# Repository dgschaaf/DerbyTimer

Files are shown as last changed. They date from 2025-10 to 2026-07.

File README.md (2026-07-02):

# DerbyTimer

Pinewood derby timing and race track control system.

**Author:** Darren Schaaf  
**Documentation guide:** [docs/README.md](docs/README.md)

---

## System Overview

DerbyTimer is a two-controller embedded system that manages the complete lifecycle of a pinewood derby race -- from staging and countdown through finish line detection and result display.

```
[Start Controller]  ──── UART 115,200 baud ────  [Finish Controller]
 Arduino Nano (ATmega328P)                         Arduino Nano 33 BLE (nRF52840)
 Custom PCB shield                                 Custom PCB shield
```

The **Start Controller** manages gates, lights, buttons, and race sequencing. The **Finish Controller** measures finish times, drives result displays, and determines the winner. Both run independent state machines that stay synchronized over a serial protocol.

---

## Race Modes

| Mode | Behavior |
|---|---|
| Gate Drop | Both gates release simultaneously; no reaction time |
| Reaction Time | Cars held at gate; release time measured per lane |
| Pro Tree | Accelerated countdown sequence (400 ms steps) |
| Dial-In | BLE-activated only (Race Manager required); not accessible via the mode button. Pressing Mode while active returns to Gate Drop |

## Race State Flow

```
IDLE -> STAGING -> COUNTDOWN -> RACING -> COMPLETE -> IDLE
```

The Start Controller drives state transitions and notifies the Finish Controller via serial. Mode changes and display advances can also be triggered from the Start Controller.

---

## Start Controller

**Hardware:** Arduino Nano (ATmega328P) on a custom PCB shield  
**Documentation:** [docs/startController.md](docs/startController.md)

### Capabilities

- **Four race modes** with mode-button cycling and per-mode light patterns
- **Dual starting gates** -- electromagnet hold with spring-return solenoid (500 ms activation window)
- **Christmas Tree lights** -- dual 6-light arrays (Blue, Yellowx3, Green, Red) via 74HC595 shift register
- **Reaction time measurement** -- microsecond precision using `micros()` from gate-open to car release
- **Foul detection** -- early release during countdown logged and flagged per lane
- **Four button inputs** -- Start, Mode, Left Lane, Right Lane; hardware-debounced via Schmitt triggers on the PCB shield

Module structure, pin assignments, and timing details:
[docs/startController.md](docs/startController.md).

---

## Finish Controller

**Hardware:** Arduino Nano 33 BLE (nRF52840) on a custom PCB shield  
**Documentation:** [docs/finishController.md](docs/finishController.md)

### Capabilities

- **Optical finish sensors** -- SE61 sensors with 74HC14 Schmitt inverter for clean edges; ISR-driven with configurable active-high/low polarity
- **Minimum race time filter** -- 500 ms suppresses mechanical bounce false triggers
- **Winner determination** -- compares rounded car times; ties supported
- **Dual 5-digit seven-segment displays** -- driven via 74HC238 decoder and MC14543B BCD driver, direct GPIO
- **Display advance** -- Start Controller signals when to cycle from finish time to reaction time view
- **Car time computation** -- reaction time subtracted (normal) or added (foul) from finish time; result rounded to nearest millisecond

Module structure, pin assignments, and display driver details:
[docs/finishController.md](docs/finishController.md).

---

## Serial Communication Protocol

Shared library: `firmware/lib/shared/serialComm.cpp/.h`

12 message types over UART at 115,200 baud with ACK/NACK confirmation and
3-retry / 50 ms timeout. Shared enums (`raceState`, `raceMode`,
`countdownState`) and bitmask constants are defined in
`firmware/lib/shared/raceTypes.h`. Full message table and byte-level wire
format: [docs/protocol.md](docs/protocol.md).

---

## Hardware Design

KiCad schematics and PCB layouts are in `hardware/startBoard/` and `hardware/finishBoard/`.

### Power

| Rail | Purpose |
|---|---|
| 12V | Electromagnets and Christmas Tree lights |
| 5V | Logic (externally regulated) |
| 3.3V | Reserved (externally regulated) |
| ~1A peak | During gate return solenoid activation |

---

## Testing

Layered strategy -- run the cheapest layer first, escalate to hardware only
when the layer below passes:

- **L1 Static Analysis** -- compile with `--warnings all` + cppcheck
- **L2 Desktop Unit Tests** -- `pio test -e native`; pure logic, no hardware
- **L3 Serial Protocol Tests** -- two cross-wired Nanos (`firmware/fwTest/`)
  or a laptop UART monitor (`firmware/tools/uart_monitor.py`)
- **L4 RACE_TEST Self-Test** -- built-in; hold MODE at power-up
  (codes: [docs/race-test-codes.md](docs/race-test-codes.md))
- **L5 Debug Serial Mode** -- compile with `-DDERBY_DEBUG`
- **Hardware bring-up** -- standalone sketches in `hardware/hwTest/`

Full layer map, directory guide, and run instructions:
[docs/testing.md](docs/testing.md). Two-board bring-up procedure:
[docs/bench-test-protocol.md](docs/bench-test-protocol.md).

---

## Deployment

### Required Libraries

- Standard Arduino libraries (AVR core)
- MBED OS (Nano 33 BLE -- for interrupt support)

### Build

### Option 1 -- VS Code (recommended)

A `.vscode/tasks.json` is included. With the project open in VS Code:

- **Ctrl+Shift+B** -- compiles the Start Controller (default build task)
- **Terminal > Run Task... > Compile Finish Controller** -- compiles the Finish Controller

Requires `arduino-cli` on your PATH.

### Option 2 -- arduino-cli (command line)

```sh
arduino-cli compile --fqbn arduino:avr:nano --library firmware/lib/shared firmware/startController/startController.ino
arduino-cli compile --fqbn arduino:mbed_nano:nano33ble --library firmware/lib/shared firmware/finishController/finishController.ino
```

### Option 3 -- Arduino IDE (not recommended)

The IDE does not know about `firmware/lib/shared`, so opening the `.ino`
directly fails with `serialComm.h: No such file or directory`. To use the
IDE anyway: copy the `firmware/lib/shared/` folder into your sketchbook
`libraries/` folder (e.g. `Documents/Arduino/libraries/shared/`) and re-copy
it after every shared-library change. Boards: Start Controller = Arduino
Nano (ATmega328P); Finish Controller = Arduino Nano 33 BLE. Options 1 and 2
avoid all of this -- prefer them.

### Serial monitoring

Debug builds (`-DDERBY_DEBUG`) log at **115,200** baud. The Finish
Controller's debug output (USB) coexists with live racing -- the wire
protocol runs on Serial1 (D0/D1). The Start Controller's single UART is
shared between USB and the wire protocol: never flash or monitor the SC
over USB with the comm cable connected. Full bench procedure:
[docs/bench-test-protocol.md](docs/bench-test-protocol.md).

---

## Extending the Design

Step-by-step recipes for adding race modes and other maintenance guidelines:
[docs/startController.md](docs/startController.md) (Maintenance Guidelines
section).

---

## Known Limitations

The following are intentional v1.0 scope boundaries, not bugs:

- **BLE / Race Manager** -- The Finish Controller's Nordic radio is unused. BLE integration is planned for the `feature-raceManager` branch. Placeholder call sites are marked `// future:` in source.
- **RFID car identification** -- Not implemented in v1.0. Reserved for the `feature-rfid` branch.
- **Dial-In mode** -- Implemented in firmware but only activatable via BLE from a Race Manager. Cannot be selected via the mode button in standalone operation.
- **Growth feature branches** -- `feature-rfid` and `feature-raceManager` are design and early development branches. They are not merged to main, are not guaranteed to compile, and are not part of v1.0 scope.

---

## Growth Features (In-Progress Branches)

The following capabilities are under active development on separate branches and are not part of the v1.0 release:

### RFID Car Identification (`feature-rfid`)

Dual RC522 RFID readers on the Start Controller shield identify individual cars at staging. Car IDs are transmitted to the Finish Controller and stored in `RaceResults`. This enables per-car timing history and automatic lane assignment.

### Race Manager (`feature-raceManager`)

A Raspberry Pi-based race management system that receives results from the Finish Controller via BLE (Nordic radio on the Nano 33 BLE). The Race Manager software lives in `software/raceManager/` and uses Python and SQLite for race data storage, bracket management, and results reporting.

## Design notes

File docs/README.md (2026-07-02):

# DerbyTimer Documentation Guide

Map of everything under `docs/`. Each document opens with a line stating what
it is and what is authoritative for its subject (usually the firmware source).
The domain glossary -- the project's shared vocabulary for heats, runs, fouls,
and the rest -- lives at the repo root in [CONTEXT.md](../CONTEXT.md).

## Design references

| Document | What it is | Read it when |
| --- | --- | --- |
| [startController.md](startController.md) | As-built design of the Start Controller (gates, lights, buttons, countdown, reaction timing) | Working on `firmware/startController/` |
| [finishController.md](finishController.md) | As-built design of the Finish Controller (sensors, timing math, displays, winner logic) | Working on `firmware/finishController/` |
| [protocol.md](protocol.md) | Byte-level UART wire protocol between the two controllers | Implementing or debugging anything that touches the serial link |
| [raceManager.md](raceManager.md) | Planning baseline for the future Raspberry Pi Race Manager (BLE, roster, brackets) -- not yet implemented | Designing the raceManager feature branch |

## Testing and operations

| Document | What it is | Read it when |
| --- | --- | --- |
| [testing.md](testing.md) | Layer map of the test strategy (L1 static analysis through L5 debug mode) | Deciding which test to run, or adding tests |
| [bench-test-protocol.md](bench-test-protocol.md) | Cold-start bench procedure for two-board integration, with FTDI tap wiring and a symptom table | Bringing up or debugging real hardware |
| [race-test-codes.md](race-test-codes.md) | Printable failure-code sheet for the built-in RACE_TEST self-test | At the track; print and store with the hardware |
| [shipping-checklist.md](shipping-checklist.md) | v1.0 verification checklist from compile gate to race-day readiness | Preparing for an event |
| [test-log.md](test-log.md) | Append-only record of test runs and results | Checking what was last verified, and when |

## Decision records ([adr/](adr/))

Architecture Decision Records: the reasoning behind choices the code cannot
explain by itself. Add a new ADR when a decision would otherwise get
re-litigated.

| ADR | Decision |
| --- | --- |
| [ADR-0001](adr/ADR-0001-pure-computation-stays-in-owning-controller.md) | Pure computation stays in its owning controller file; file boundaries map to hardware interfaces |
| [ADR-0002](adr/ADR-0002-foul-derived-from-timestamps.md) | Foul status is derived from timestamps, not stored as a flag |
| [ADR-0003](adr/ADR-0003-tx-fifo-queue-design.md) | TX FIFO queue with a single in-flight message |
| [ADR-0004](adr/ADR-0004-heat-abort-criteria.md) | Heat abort criteria and forceIdle semantics |
| [ADR-0005](adr/ADR-0005-serial-protocol-structure.md) | Serial protocol structure: framing, ACK/NACK discipline, baud choice |
| [ADR-0006](adr/ADR-0006-statemachine-service-model-and-outbox.md) | State machine declare-intent interface (request/service) and shared Outbox direction |

## Diagrams ([diagrams/](diagrams/))

Sources only -- no rendered images are committed. `.puml` files need a
PlantUML viewer (VS Code: the "PlantUML" extension); `.drawio` files open at
diagrams.net or with the "Draw.io Integration" VS Code extension.

| Diagram | Shows |
| --- | --- |
| [stm_startController.puml](diagrams/stm_startController.puml) | Start Controller state machine |
| [stm_finishController.puml](diagrams/stm_finishController.puml) | Finish Controller state machine |
| [stm_raceManager.puml](diagrams/stm_raceManager.puml) | Planned Race Manager state machine |
| [seq_stateMachine.puml](diagrams/seq_stateMachine.puml) | Coordinated state-transition protocol (selfTransition / rxTransition) |
| [seq_idle.puml](diagrams/seq_idle.puml), [seq_staging.puml](diagrams/seq_staging.puml), [seq_countdown.puml](diagrams/seq_countdown.puml), [seq_racing.puml](diagrams/seq_racing.puml), [seq_complete.puml](diagrams/seq_complete.puml) | SC-FC message sequence in each race state |
| [activity_countdown.puml](diagrams/activity_countdown.puml) | RACE_COUNTDOWN activity flow on the Start Controller |
| [timing_reactionTime.puml](diagrams/timing_reactionTime.puml) | Reaction-time measurement model (Reaction mode) |
| [component_modules.puml](diagrams/component_modules.puml) | Firmware module dependencies |
| [class_module.puml](diagrams/class_module.puml) | Start Controller class/struct structure |
| [physical_interconnect.drawio](diagrams/physical_interconnect.drawio) | Board-to-board physical wiring |
| [power_distribution.drawio](diagrams/power_distribution.drawio) | Power rails and distribution |

`Track Architecture.pdf` (with its Visio source `Track Architecture.vsdx`) is
the top-level physical track layout.

## Hardware spec sheets ([hardware_spec_sheets/](hardware_spec_sheets/))

Vendor datasheets, pinouts, and schematics for the Arduino Nano (A000005) and
Nano 33 BLE (ABX00071), plus the legacy commercial track design files the
project started from. Reference material only; nothing here is
project-authored.

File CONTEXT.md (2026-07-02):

# DerbyTimer

A two-controller embedded timing system for pinewood derby races, managing the full lifecycle of a heat from staging through finish line detection and result display.

## Language

**Heat**:
One complete run -- a single IDLE -> STAGING -> COUNTDOWN -> RACING -> COMPLETE -> IDLE cycle. The atomic unit of competition.
_Avoid_: Race (as a synonym for heat), run

**Event**:
A full race night consisting of multiple heats across time trials and a bracket.
_Avoid_: Race night, tournament, derby (as a synonym for event)

**Race Time** (`raceTimeUs`):
Elapsed time from the GO signal to the car crossing the finish line. The race clock.
_Avoid_: Finish time, raw time

**Reaction Time** (`reactionTimeUs`):
Elapsed time from the GO signal to the gate dropping (the driver's response). Measured at the Start Controller.
_Avoid_: Response time, driver time

**Car Time** (`carTimeUs`):
Elapsed time from the gate dropping to the car crossing the finish line. The car's performance stripped of human factors. Equals Race Time minus Reaction Time for a clean start. The value shown on the display and used for winner determination. Not displayed for a disqualified lane.
_Avoid_: Adjusted time, corrected time

**Foul**:
A gate drop that occurs before the GO signal in a reaction-mode heat. Disqualifies that lane -- no time is shown on the display and the lane cannot win. Not a time penalty.
_Avoid_: Early start, false start

**Run**:
One result attributed to a single car from a single heat, in the context of time trials. The car's viewpoint. One heat always produces exactly two runs (one per lane).
_Avoid_: Attempt, pass, heat (when describing a per-car result)

**Time Trial**:
The gate-drop phase of an event where each racer accumulates individual runs to establish their best time. Heats run in any order; the Race Manager matches results to racers by Car ID. Trophy is awarded to the fastest time trial car.
_Avoid_: Qualifying, practice rounds, seeding rounds

**Bracket**:
The single-elimination phase of an event run in Reaction or Pro Tree mode. All non-scratched cars enter. Seeded by time trial best times -- top-seeded cars receive byes as needed to fill the bracket to the next power of 2. Bragging rights go to the bracket winner.
_Avoid_: Elimination rounds, finals

**Car**:
The primary racing entity -- the physical vehicle that competes. Used everywhere in race results, brackets, time trials, lane assignments, and RFID identification. A car belongs to a specific racer for one event year.
_Avoid_: Racer (when referring to what's on the track or in results)

**Racer**:
The person behind the car. Used only when referring explicitly to name, personal identity, lifetime records, or club membership. A racer has a different car each year; the car is the annual entity, the racer is the persistent one.
_Avoid_: Car (when referring to the person's name or persistent identity)

**Trigger**:
A handheld momentary push-button on a cable (~6 ft), approximately the size of a can of pop. There are three triggers: Left (driver), Right (driver), and Starter (race official). Hardware-debounced via Schmitt triggers on the PCB shield. In the firmware the Left and Right triggers are referred to as "buttons" (`isLeftPressed()`, `isRightPressed()`); the Starter trigger is `isStartPressed()`. All three are press-and-release (no hold required).
_Avoid_: Button (in design discussions -- use Trigger for handheld controls and Mode Button for the panel control)

**Mode Button**:
A momentary push-button mounted on the enclosure shell. Cycles the race mode in IDLE (Gate Drop -> Reaction -> Pro Tree and back), and returns to IDLE from STAGING. Intentionally positioned inconveniently -- it is a software escape hatch, not a normal race-flow control. Operators are not expected to use it to abort a heat mid-run; the correct response to a "driver not ready" situation is to let the heat play out and have the Race Manager retroactively nullify it. In firmware referred to as `isModePressed()`.
_Avoid_: Mode trigger, abort button

**Starter**:
The race official who operates the Starter Trigger to advance the race state (IDLE -> STAGING -> COUNTDOWN). Distinct from the drivers, who each hold their own lane Trigger. Not a role defined in the firmware -- the firmware sees only button inputs, not who pressed them.

**Lane**:
One of the two physical track positions -- Left and Right. Permanent fixture names in the firmware (sensors, electromagnets, solenoids). Also used to refer to the car and racer occupying that position during a heat; the context makes the meaning clear.
_Avoid_: Track (as a synonym for lane), Lane 1 / Lane 2

**Matchup**:
A scheduled bracket pairing of two specific racers. A matchup becomes a heat when it runs on the track.
_Avoid_: Pairing, race (as a synonym for matchup), round

**Scratch**:
A racer officially withdrawn from further competition. Scratched racers are excluded from bracket seeding and generation. Their completed runs remain in the database. Operator-applied at any point before or during the bracket.
_Avoid_: Forfeit, dropout, DNS (as a permanent state)

**Bye**:
An automatic advancement in the bracket when a racer has no eligible opponent (e.g. odd bracket size, opponent scratched). The active racer advances without racing.

**Rerun**:
A bracket heat that produced no valid result because both lanes fouled. The matchup is immediately returned to the front of the queue as "now racing." No database record is written until a valid result (one or fewer fouls) is produced. The Race Manager triggers a rerun when it receives a No Result signal from the firmware.
_Avoid_: Void (which is operator-initiated), re-race

**No Result**:
The firmware signal for a heat that produced no valid winner -- currently double-foul, and in future any aborted or interrupted heat. Transmitted as a distinct value in the `MSG_WINNER` payload (a new bitmask constant `winner_noResult`, separate from `winner_tie`). The Race Manager interprets No Result as a Rerun in bracket context or two void runs in time trial context.
_Avoid_: DNF (cars do complete the track), tie (which is a separate outcome for two clean cars finishing at equal times), incomplete

**Best in Show**:
A subjectively judged award for car design, creativity, craftsmanship, humor, or other qualities -- entirely independent of race results. Judged by an external panel (not the operator). Up to three places per division; 2nd and 3rd are optional. Operator enters winners manually after judging. Not calculated from race data.
_Avoid_: Design award, appearance award

**Division**:
An age grouping used exclusively for Best in Show awards -- not for race format or bracket structure. All cars race together regardless of division. Configured per event: zero, one, or two divisions. Current typical split when two divisions are used: Younger (3rd-5th grade) and Older (6th-8th grade).
_Avoid_: Age group, category (as a synonym for division)

**Dial-In** (DIALIIN):
A future race mode where the Race Manager applies a per-car handicap to stagger gate drops (or reaction triggers) so that all cars theoretically arrive at the finish line simultaneously. The Race Manager first accumulates each car's average time from gate-drop heats, then computes handicaps and controls the precise start timing for each lane. Intended as a pure reaction mode -- drivers still trigger their own gates, but the Race Manager staggers the GO signal per lane. Requires a hardware revision to support independent per-lane countdown light control (current hardware shares all yellow and green lights across both lanes). Not implemented in firmware beyond the mode stub; architecture must not preclude it.
_Avoid_: Handicap mode (use Dial-In), staggered start (use handicap)

**Handicap**:
A per-car time offset in Dial-In mode, calculated by the Race Manager from that car's average race time across time trials. Applied by staggering when each lane's start signal fires so that all cars are expected to reach the finish line simultaneously. Stored and calculated by the Race Manager; the firmware receives the resulting timing commands over BLE.
_Avoid_: Head start, time penalty, offset

## Relationships

- An **Event** contains many **Heats**, organized into **Time Trials** and a **Bracket**
- A **Heat** produces exactly one result (winner, finish times, fouls) and exactly two **Runs** (one per lane)
- A racer's time trial is complete when they have accumulated the configured number of **Runs** (default: 5)
- The firmware executes individual **Heats** in whatever mode is configured; it has no awareness of **Time Trial** vs **Bracket** -- that distinction belongs to the Race Manager

## Example dialogue

> **Dev:** "So when a car fouls in a bracket heat, does the Race Manager record the heat?"
> **Darren:** "No -- the fouling car is disqualified and the opponent wins. One foul is a valid result. But if both cars foul it's a rerun -- no result is recorded and the matchup goes back to the front of the queue."
> **Dev:** "Got it. And for time trials -- if Car #12 has done 3 of 5 runs and the kid's dad scratches them, what happens to those 3 runs?"
> **Darren:** "They stay in the database, the car just doesn't get seeded into the bracket."
> **Dev:** "And the Car Time on the display after a clean reaction-mode heat -- that's gate-drop to finish, not green-light to finish?"
> **Darren:** "Correct. Race Time is green to finish, Reaction Time is green to gate-drop, Car Time is gate-drop to finish. Car Time is what we care about -- it's the car's performance without the driver's reaction in it."

## Flagged ambiguities

- "race" is used in firmware naming (`raceState`, `raceMode`, `raceResults`) to mean **Heat** -- this is implementation naming only; use **Heat** in documentation and design discussions.
- Foul lanes on the track displays: **blank the foul lane on both the car-time and reaction-time screens** (option B, resolved). A foul is an automatic loss, so the time is irrelevant -- showing one invites petty "I was only 0.5 seconds early" arguments -- and the BCD hardware cannot label a number as "early jump time" vs. "reaction time," so any number shown for a DQ'd lane risks confusion with the clean lane's result. Foul coaching data (how early the driver jumped) belongs in the Race Manager UI where it can be labeled properly. The firmware's `displayReactionTimes()` must blank foul lanes, consistent with `displayCarTimes()`.
- "car" and "racer" are sometimes used interchangeably in casual speech -- resolved: **Car** is the primary entity in all race data; **Racer** is reserved for when the person's name or persistent identity is the subject.
- Dial-In mode requires per-lane countdown light control, which the current hardware does not support (all yellow and green lights share a single shift register output). Any firmware work on Dial-In must be preceded by a hardware revision. This constraint is not captured in the firmware or PCB docs yet.
- The lane displays use the MC14543B BCD-to-7-segment decoder, which can only output digits 0-9 and blank. No alphabetic characters (no "DNF", "ERR", "FLt", etc.) are possible. Display design choices are constrained to numbers and blank.
- A lane that does not cross the finish line within maxRaceTimeUs (10 s) is shown as 9.999 on the display. This is intentional: it is the maximum measurable time, provides positive operator confirmation that the heat has ended, and is the only option given the BCD hardware. The Race Manager must treat a received time of exactly maxRaceTimeUs as a DNF sentinel, not a real measurement.

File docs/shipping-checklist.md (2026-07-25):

# DerbyTimer v1.0 Shipping Checklist

Work through these sections in order. Each section can be checked off independently as hardware becomes available. Serial protocol correctness (fwTest) is a prerequisite for the hardware integration section and is tracked separately.

---

## 1. Firmware -- Compile Gate

Do this at your desk before touching hardware.

- [ ] `startController` compiles clean, zero warnings
- [ ] `finishController` compiles clean, zero warnings
- [ ] All critical and high-priority items in the project backlog are resolved or explicitly accepted
- [ ] Fresh flash to both controllers from the same build

---

## 2. Bench -- Sensor Verification

Wire one SE61 sensor to A0 or A1 on the FC. Power the sensor. Confirm with serial monitor.

- [ ] `armSensors()` attaches interrupt without error
- [ ] Physically break the beam -> `isLeftFinished()` / `isRightFinished()` returns true
- [ ] Break beam immediately at arm time -> confirm 500 ms filter suppresses it (flag stays false)
- [ ] Confirm `config.activeHigh = true` matches your sensor wiring (beam-break = pin HIGH)
- [ ] Both lanes independently verified

---

## 3. Bench -- Display Verification

Connect one MC14543B + 74HC238 + display assembly. Power it. Confirm visually.

- [ ] All five digit positions illuminate correctly (no stuck segments, no ghosting between digits)
- [ ] Decimal point appears between digit 1 and digit 2 (ones and tenths -- e.g., `X.XXX`)
- [ ] `0b1111` BCD input blanks the digit cleanly -- no partial segments lit
  - If it does NOT blank: use the blanking pin (BI/RBO) instead and update `writeBlankDigit()`
- [ ] 30 us settle time is adequate -- digits don't bleed into adjacent positions at speed
- [ ] Repeat for the second lane display
- [ ] Error sentinel `88.888` displays correctly (all eights)

---

## 4. Integration -- Controllers Talking (prerequisite: fwTest complete)

Two controllers wired over UART, all peripherals connected. No track yet.

- [ ] IDLE -> STAGING: blue lights on SC, gates return, displays clear
- [ ] STAGING -> IDLE via Mode button: lights off, gates stay returned
- [ ] Buttons act on release: hold Start or Mode down and confirm nothing happens until it is let go
- [ ] Held button does not carry over: hold Mode to abort STAGING, keep holding into IDLE -> race mode must NOT advance
- [ ] STAGING -> COUNTDOWN blocked until both gates confirm up (`areLanesReady()`)
- [ ] COUNTDOWN: Y3 -> Y2 -> Y1 -> GO sequence fires at correct intervals (500/500/500 ms)
- [ ] PRO mode: all three yellows light simultaneously on Y1 stage (400 ms single stage)
- [ ] Mode indicator blinks 3x in IDLE when mode changes
- [ ] GATEDROP: gates drop at GO; FC arms sensors; heat runs to completion
- [ ] Winner announced: left-win, right-win, and tie light patterns all verified
- [ ] Display advance (Start press in COMPLETE) cycles to reaction times, then IDLE
- [ ] Double-foul: both fouls sent -> `winner_noResult` -> no win lights, IDLE on next Start press
- [ ] One DNF (block one sensor for 10+ seconds): correct lane blanked, other lane displays time

---

## 5. Integration -- Fault Recovery

These verify the abort paths hold up on real hardware.

- [ ] COUNTDOWN abort via Mode click: tree goes dark, gates drop, NO red blink (operator action, not a fault)
- [ ] COUNTDOWN stall watchdog: with the FC disconnected, a countdown that cannot reach GO aborts to IDLE within ~5 s AND blinks red 3x
- [ ] Unplug UART cable during COUNTDOWN -> FC 10 s timeout fires -> both controllers return to IDLE independently
- [ ] Re-plug cable, run a normal heat -> system recovers cleanly with no stale state
- [ ] Power-cycle SC mid-heat -> FC eventually times out or DNFs -> operator can restart

---

## 6. Race Mode Sign-Off

Run at least one complete heat in each mode, end to end.

- [ ] MODE_GATEDROP -- both cars finish, winner correct
- [ ] MODE_REACTION -- car times displayed, reaction times on second Start press
- [ ] MODE_PRO -- single-stage countdown, car times displayed, reaction times on second Start press
- [ ] REACTION foul: one car triggers before GO -> red light on that lane -> foul lane blanked, other lane wins

---

## 7. Physical / Electrical

- [ ] All connectors crimped and fully seated
- [ ] UART cable run at full race-track length -- confirm no serial errors at 115,200 baud
- [ ] Gate electromagnets drop cleanly on de-energize (gravity + spring, no rebound catch)
- [ ] Return solenoid returns both gates within the 500 ms window
- [ ] Power supply adequate under full load: both controllers + gates + lights + displays simultaneously
- [ ] No shorts or heat issues after 30 min of continuous operation

---

## 8. Race-Day Readiness

- [ ] Fresh firmware flash the day before (eliminates "which version is on there?" questions)
- [ ] Full dry run: 4-6 back-to-back heats across multiple modes, no errors
- [ ] Laptop on-site with `arduino-cli` and both `.ino` files ready for emergency reflash
- [ ] USB cables for both Nanos packed
- [ ] Project backlog reviewed -- no surprise open high-priority items

---

## Known Accepted Limitations for v1.0

These are documented decisions, not forgotten items:

- **Stuck-closed button reads as a dead control** -- Start and Mode act on the release edge, so a button held closed by a mechanical fault produces no action at all rather than a stuck-on one. The self-test button check is the mitigation; run it if a control seems unresponsive.
- **No Race Manager** -- Win/loss is read from the FC display and lights. Bracket tracking is manual.
- **No RFID** -- Car identification is visual. Lane assignment is by physical position.
- **Display resolution is 1 ms** -- Sub-millisecond timing differences are rounded. This is typical for pinewood derby.

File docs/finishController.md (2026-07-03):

# Finish Controller Design Notes

> As-built design reference. The firmware in `firmware/finishController/src/` is
> authoritative; this document explains the design and the reasoning behind it.

This document summarizes the design of the finish controller firmware for a hobbyist Pinewood-Derby timing system. The **finish controller** complements a separate start controller and reports race results to a future **race manager** (a Raspberry Pi via BLE). It measures finish times, combines them with start reaction times, determines the winner, and drives large seven-segment displays.

---

### Hardware Overview

* **Controller** -- An **Arduino Nano 33 BLE** (nRF52840) runs the finish controller firmware. It communicates with the **start controller** over a UART defined in *serialComm* and will later talk BLE to the race manager.
* **Finish sensors** -- Each lane has an **SE61** optical sensor with an external pull-up resistor. The signals pass through a **74HC14** Schmitt inverter on the shield to provide clean edges. A configurable *activeHigh* flag in the sensors module selects whether the interrupt triggers on a rising or falling edge. A minimum race time (*minRaceTimeUs* = 500,000 us) filters out spurious triggers during the first 0.5 s; *maxRaceTimeUs* = 10,000,000 us auto-completes a lane after 10 s.
* **Display driver** -- Each lane's 5-digit seven-segment display is driven directly via GPIO rather than through shift registers. The BCD digit value is placed on four output lines (AD0-AD3, pins D5-D8) connected to **MC14543B** BCD-to-7-segment drivers. The digit position is selected by three address lines (A0-A2, pins D2-D4) connected to a **74HC238** 3-to-8 demultiplexer. A single decimal-point line (pin D9) is toggled per digit. Lane selection uses dedicated enable pins: A2 (PIN_LANE1) enables the left-lane 74HC238, and A3 (PIN_LANE2) enables the right-lane 74HC238.

---

### Sensor Handling

The *sensors* module encapsulates finish sensor handling:

* A *SensorConfig* structure defines *leftPin* (A1), *rightPin* (A0), *activeHigh* polarity, and time filters (*minRaceTimeUs* and *maxRaceTimeUs*). Pin assignments can be changed without touching the rest of the code.
* *setupSensors*() configures pin modes but does not attach interrupts. Interrupts are attached in *armSensors*() and detached in *disarmSensors*() to minimise spurious triggers when idle.
* When a race starts, *armSensors*(*startMicros*) records the absolute start time and attaches interrupts on the correct edge. The ISRs record the elapsed time (*micros() - start*) only once per lane; triggers within *minRaceTimeUs* are ignored to prevent bounce false-starts.
* Volatile flags *leftFinished* / *rightFinished* are exposed for polled access. Helper functions *isLeftFinished*(), *isRightFinished*(), *getLeftTimeUs*(), and *getRightTimeUs*() provide safe access to the recorded times.

---

### Race Logic

Race state transitions are driven externally via messages from the start controller. The finish controller participates actively during *RACE_COUNTDOWN*, *RACE_RACING*, and *RACE_COMPLETE*.

**RACE_COUNTDOWN** -- *rx.RaceStart* is cleared at IDLE entry via `rx.clearHeatEvents()`, so it is already false when COUNTDOWN is entered. When *rx.RaceStart* arrives from the start controller, *micros*() is captured as `timingInputs.startUs` and *armSensors*() is called. The state transitions to *RACE_RACING* when the start controller sends the matching state change.

**RACE_RACING** -- On entry, recording flags and times are reset. Sensors are armed if not already armed from COUNTDOWN. Each loop iteration:

1. *handleSensors*() polls *isLeftFinished*() / *isRightFinished*() and records finish times. If *maxRaceTimeUs* elapses before a sensor triggers, the lane is flagged as DNF (`timingInputs.leftDnf`/`rightDnf` set true) and `maxRaceTimeUs` is stored as a placeholder time.
2. *handleRxReaction*() reads `rx.LeftReactionTime`, `rx.RightReactionTime`, `rx.LeftFoul`, `rx.RightFoul` from the *SerialRxState* struct (updated by *rxSerial*()) and stores them in `heatResult` (`HeatResults`). Reaction times are stored as `uint32_t`; companion flags `rx.LeftReactionValid` / `rx.RightReactionValid` indicate whether a value has been received this race (both cleared to `false` at IDLE entry via `rx.clearHeatEvents()`).
3. Once both lanes are recorded, *stm.target* is set to *RACE_COMPLETE* and the state machine transitions.

**RACE_COMPLETE** -- On entry:

1. *computeHeatResults*(`heatResult`, `timingInputs`) completes the `HeatResults` struct in-place. `heatResult.left.foul` and `heatResult.left.reactionTimeUs` (and right) are already populated from RACING via *handleRxReaction*(). The function adds the remaining derived fields:
   * `raceTimeUs` -- copied from `timingInputs` (ISR-captured elapsed time)
   * `carTimeUs = raceTimeUs + (foul ? +1 : -1) * reactionTimeUs` -- a foul adds reaction time; a clean start subtracts it
   * `dnf` -- true if the lane timed out (car did not reach the sensor); `carTimeUs` is meaningless for DNF lanes
   * `winner` -- false if the lane fouled or DNF'd; otherwise true if the opponent is invalid or this lane's `carTimeUs` is lower
2. *displayCarTimes*() calls `updateDisplay(carTimeUs, lane)` for each lane. Foul and DNF lanes are blanked. `needReact` is set only when at least one lane is valid (non-foul, non-DNF) and the mode requires reaction display.
3. *MSG_WINNER* is sent with a bitmask (`bit 0 = left wins, bit 1 = right wins, bit 2 = tie, bit 3 = no result`) and handed to the Outbox for delivery tracking. Bit 3 fires when both lanes are invalid (double-foul, double-DNF, or one of each); bit 2 fires only for a genuine simultaneous finish. The Outbox retries the message once on a send failure, then drops it silently -- the finish times are already on the displays, so a lost winner only costs the start controller's win-light animation.

On subsequent *MSG_DISP_ADVANCE* events (triggered by the operator pressing Start on the start controller):

* If *needReact* is true: *displayReactionTimes*() is called and *needReact* is cleared.
* Otherwise: the state machine targets *RACE_IDLE* and calls *txRaceState(RACE_IDLE)* to coordinate return to idle with the start controller.

---

### State and Mode Variables

State is managed by a local `stateMachine` struct (`stm`) within *finishController.cpp*. It holds *current*, *target*, *entry*, and *exit* flags. The allowed transition table is:

| From \ To | IDLE | STAGING | COUNTDOWN | RACING | COMPLETE | TEST |
|---|:----:|:---:|:---:|:---:|:---:|:----:|
| IDLE | | Y | | | | Y |
| STAGING | | | Y | | | |
| COUNTDOWN | | | | Y | | |
| RACING | | | | | Y | |
| COMPLETE | Y | | | | | |
| TEST | Y | | | | | |

The current race mode is held in *currentMode* (local to *finishController.cpp*) and kept in sync with `rx.Mode` from the start controller.

---

### Display Design

The firmware drives two 5-digit seven-segment displays via direct GPIO. `updateDisplay(uint32_t timeUs, Lane lane)` performs:

1. Round time to the nearest millisecond: `tMs = (timeUs + 500) / 1000`. Clamp at 99,998 ms to prevent a 6-digit overflow.
2. Extract five digits: tens, ones, tenths, hundredths, thousandths (e.g. 1,234 ms -> 0, 1, 2, 3, 4).
3. Select the target lane by driving PIN_LANE1 (A2) or PIN_LANE2 (A3) LOW (active-low enable on the 74HC238).
4. For each digit, call `writeDigit(idx, val, showDecimal)`:
   * Set the decimal-point pin (D9) HIGH only for digit index 1 (between ones and tenths).
   * Drive address pins D2-D4 with the digit index (A0/A1/A2 on the demux).
   * Drive data pins D5-D8 with the 4-bit BCD value (AD0-AD3 on the MC14543B).
   * Wait 30 us for the MC14543B latch to settle.
5. Disable both lane pins HIGH after all digits are written.

`clearDisplay(Lane lane)` follows the same lane-select sequence but writes BCD `1111` (0xF) to all five positions, which the MC14543B interprets as a blank.

#### Pin Summary

| Signal | Pin | Description |
|---|-----|---|
| PIN_BCD_MUX_A | D2 | Digit address bit 0 (74HC238 A0) |
| PIN_BCD_MUX_B | D3 | Digit address bit 1 (74HC238 A1) |
| PIN_BCD_MUX_C | D4 | Digit address bit 2 (74HC238 A2) |
| PIN_AD0 | D5  | BCD data bit 0 (MC14543B AD0) |
| PIN_AD1 | D6  | BCD data bit 1 (MC14543B AD1) |
| PIN_AD2 | D7  | BCD data bit 2 (MC14543B AD2) |
| PIN_AD3 | D8  | BCD data bit 3 (MC14543B AD3) |
| PIN_DECIMAL  | D9  | Decimal point (active HIGH) |
| PIN_LANE1 | A2  | Left-lane 74HC238 enable (active LOW)|
| PIN_LANE2 | A3  | Right-lane 74HC238 enable (active LOW)|

---

### Communication with Start Controller

The finish controller communicates with the start controller over a serial connection handled by *serialComm*. The protocol defines **12 message types** (MSG_NULL through MSG_DISP_ADVANCE). Key elements:

* **`rxSerial()`** -- Called on every loop iteration. Parses incoming messages and updates the global `SerialRxState rx` struct. Fields used by the finish controller include `rx.State`, `rx.Mode`, `rx.RaceStart`, `rx.LeftFoul`, `rx.RightFoul`, `rx.LeftReactionTime`, `rx.RightReactionTime`, `rx.LeftReactionValid`, `rx.RightReactionValid`, and `rx.DisplayAdvanceFlag`.
* **`txWinner(uint8_t winnerMask)`** -- Sends MSG_WINNER to the start controller. Bit 0 = left wins, bit 1 = right wins, bit 2 = tie (genuine simultaneous finish), bit 3 = no result (double-foul, double-DNF, or one of each).
* **`txRaceState(raceState newState)`** -- Requests a coordinated state change. Used by the finish controller to initiate the return to RACE_IDLE from RACE_COMPLETE. Transitions are committed only when the start controller sends an ACK; TX_TIMEOUT or TX_FAILED causes the attempt to be abandoned.
* **`txService()`** -- Drives the TX FIFO queue; must be called once per main loop. Callers enqueue with `tx*()` functions and poll outcome with `txStatusOf(serialMsgID)`.

All TX functions use a single-in-flight FIFO queue with 3 retries and a 50 ms per-attempt timeout (`txTimeout = 50`). MSG_RACE_START is priority and jumps to the front of the queue.

---

### Communication with Race Manager (BLE)

The Nano 33 BLE includes a Nordic BLE radio. The BLE protocol and characteristic layout are not yet defined. When implemented, race results (*carTimeUs*, *raceTimeUs*, *reactionTimeUs*, *foul*, *dnf*, *winner*) should be transmitted once the race completes. Placeholder comments in *finishController.cpp* (e.g. `// notifyBLEMode(currentMode)`) mark integration points.

---

### Deferred Scope

* **BLE / Race Manager** -- The GATT service is not yet defined; the full plan
  lives in [raceManager.md](raceManager.md). Placeholder comments in
  *finishController.cpp* mark the integration points. BLE callbacks must not
  block timing-critical sections.
* **RFID car ID** -- Car identification is deferred to the `feature-rfid`
  branch. `LaneResult` will need a `carID` field once RFID is implemented.

Hardware bring-up verification (display wiring polarity, BCD 0xF blanking,
sensor min-time filtering) is covered by
[shipping-checklist.md](shipping-checklist.md) and
[bench-test-protocol.md](bench-test-protocol.md).

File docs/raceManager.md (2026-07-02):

# Race Manager Design

> **Status:** Planning -- not yet implemented. `firmware/raceManager/` is a stub placeholder.
> This document captures the intended design and serves as the planning baseline for implementation.
>
> **Branch strategy:** raceManager is its own major feature branch. RFID firmware (a separate major feature branch) is a prerequisite and is assumed to be merged before raceManager work begins.

---

## Overview

The Race Manager is a **full-screen kiosk application** running on a **Raspberry Pi** that serves as the event-level coordinator for a Pinewood Derby race day. It connects wirelessly (BLE) to the Finish Controller, manages the roster, coordinates race modes and heat scheduling, displays race results in real time, and persists results across years.

The two Arduino controllers own all real-time hardware concerns (timing, gate control, sensors, track display). The Race Manager handles everything above that layer: who is racing, in what order, in which mode, what the standings are, and how results are communicated to participants and organizers.

### What the Race Manager does NOT do

- Control gates or start/stop races (that is the Start Controller's job)
- Measure times (that is the Finish Controller's job)
- Drive the per-lane numeric displays at the track (that is the Finish Controller's job)

---

## Repository Paths

| Component | Path |
| --- | --- |
| Race Manager application (RPi) | `software/raceManager/` |
| Finish Controller firmware (BLE additions) | `firmware/finishController/` |
| Stub placeholder (current) | `firmware/raceManager/` -- to be removed or repurposed |

---

## Hardware Platform

| Component | Detail |
| --- | --- |
| **Computer** | Raspberry Pi (model TBD -- Pi 4 or Pi 5 recommended) |
| **Display** | HDMI monitor; application runs full-screen |
| **Input** | USB keyboard and mouse (wireless dongle acceptable) |
| **Camera** | USB camera -- *deferred/backlog*, see [Deferred Features](#deferred-features--backlog) |

The application should auto-launch on boot in kiosk mode, bypassing the graphical desktop. The operator has an in-app option to quit to the Raspberry Pi OS if needed (e.g. for maintenance or updates).

---

## System Context

```
[Start Controller]  ─── UART 115200 ───  [Finish Controller]
 Arduino Nano                              Arduino Nano 33 BLE
 ATmega328P                                nRF52840
                                               │
                                         BLE (GATT)    <- not yet implemented
                                         bidirectional
                                               │
                                       [Race Manager]
                                        Raspberry Pi
                                       (this document)
```

BLE is bidirectional. The Finish Controller notifies the Race Manager of state changes, car IDs, and results. The Race Manager can write race mode and test commands to the Finish Controller when the system is idle.

---

## BLE Interface

The Nano 33 BLE (nRF52840) exposes a GATT service. The Race Manager acts as the BLE central and connects by service UUID. Placeholder comments in `finishController.cpp` (e.g. `// notifyBLEMode(currentMode)`) mark the integration points.

BLE range is expected to be 10-20 feet in a church gym, which is well within BLE 5.0 capability.

### Proposed GATT Service: Derby Race Service

> UUIDs are planning proposals -- assign final values at implementation time.

| Characteristic | Direction | Type | When Sent |
| --- | --- | --- | --- |
| **Handshake** | RM <-> FC (read/write) | `uint8_t` | On connection; RM confirms it is talking to the right device |
| **Race State** | FC -> RM (notify) | `uint8_t` | On every state transition (`RACE_IDLE` ... `RACE_COMPLETE`) |
| **Race Mode** | FC -> RM (notify) | `uint8_t` | When mode changes (`MODE_GATEDROP`, `MODE_REACTION`, `MODE_PRO`, `MODE_DIALIIN`) |
| **Car IDs** | FC -> RM (notify) | `uint8_t[2]` | On `RACE_STAGING` entry: `[leftCarID, rightCarID]` from RFID |
| **Heat Result** | FC -> RM (notify) | struct | On `RACE_COMPLETE` entry -- see payload below |
| **Heartbeat** | FC -> RM (notify) | `uint32_t` | Every ~1 s; RM detects connection loss if absent |
| **Malfunction** | FC -> RM (notify) | `uint8_t` | On `MSG_ERROR` or `criticalTxError`; carries error code |
| **Set Mode** | RM -> FC (write) | `uint8_t` | RM selects race mode -- **only accepted when `RACE_IDLE`** |
| **Initiate Test** | RM -> FC (write) | `uint8_t` | RM triggers `RACE_TEST` -- **only accepted when `RACE_IDLE`** -- *deferred* |
| **Test Result** | FC -> RM (notify) | TBD | Test outcome data -- *deferred* |

### Heat Result Payload

```c
struct BLEHeatResult {
    uint8_t  heatID;                // Assigned by RM, echoed back; 0 if unmanaged
    uint8_t  carIDLeft;             // RFID car ID; 0 if not yet implemented
    uint8_t  carIDRight;
    uint32_t carTimeUsLeft;         // Final car time (reaction-adjusted), us
    uint32_t carTimeUsRight;
    uint32_t raceTimeUsLeft;        // Raw sensor time, us
    uint32_t raceTimeUsRight;
    uint32_t reactionTimeUsLeft;    // us; see OQ-RM4 for how to signal "not applicable"
    uint32_t reactionTimeUsRight;
    uint8_t  foulMask;              // bit0 = left foul, bit1 = right foul
    uint8_t  winnerMask;            // bit0 = left wins, bit1 = right wins, bit2 = tie, bit3 = no result (double foul / aborted)
};

// Note: foul reaction time (how early the driver jumped) is included in reactionTimeUsLeft/Right
// even for foul lanes. The track display blanks foul lanes (BCD hardware cannot label the number),
// but the Race Manager SHOULD surface foul reaction time with a proper label ("jumped X.XXX s early")
// as coaching feedback. Use foulMask to determine which lanes to label accordingly.
```

> **OQ-RM4** -- How should the BLE payload signal that reaction time is not applicable? Three candidates: (a) match the firmware's `reactionValidMask` pattern (`uint8_t`, bit0=left valid, bit1=right valid); (b) rely on `foulMask` + mode -- a foul lane has no reaction time, and GATEDROP mode has no reaction times at all, so the Race Manager can infer validity without an extra field; (c) decide based on BLE best practices once the GATT layer is being designed. Defer to Phase 1.

This mirrors data already computed in `finishController.cpp` `RACE_COMPLETE`.

### BLE Design Constraints

- BLE notify callbacks must not run inline with ISR-driven sensor handling. Queue notifications and send them after `RACE_COMPLETE` entry.
- The ArduinoBLE / mbed BLE stack shares the nRF52840 core with the Arduino sketch. Avoid contention with `display.cpp` GPIO timing (30 us digit settle).
- Bidirectional writes (Set Mode, Initiate Test) are guarded by state on the FC side -- the FC must reject writes received outside `RACE_IDLE`.

---

## Application Platform and Startup

### Technology Choice (Needs Research -- OQ-RM1)

The application needs to be a full-screen GUI running natively on the Pi. Framework candidates include Python-native (pygame, tkinter, PyQt), Node.js/Electron, or a web app served to a Chromium kiosk. No decision has been made -- research required before Phase 2 begins. Key constraints: full-screen kiosk capability, BLE central role support, bracket/tree rendering, SQLite access, and reasonable performance on a Pi 4/5.

### Kiosk Auto-Launch

- Application launches automatically at boot, before the graphical desktop
- Two approaches: `~/.config/autostart/` entry under a minimal display manager, or a `systemd` service that launches the app directly
- In-app "Quit to Desktop" button terminates the kiosk session and drops to the RPi desktop for maintenance
- In-app "Shutdown" button for clean end-of-event power-off

---

## Power-On / Session Flow

On launch, the application checks for a saved session (in-progress race day state in the local database). It presents:

```
┌─────────────────────────────────┐
│       PINEWOOD DERBY            │
│                                 │
│   [ Continue Race ]  <- only shown if saved session exists
│   [ New Race      ]
│   [ Practice      ]
│   [ Quit to OS    ]
└─────────────────────────────────┘
```

| Option | Description |
| --- | --- |
| **Continue Race** | Restore the last saved session -- roster, heats run, bracket state |
| **New Race** | Start fresh; walk through setup wizard (roster, settings, awards) |
| **Practice** | Enter Practice mode immediately -- no roster required |
| **Quit to OS** | Exit application to Raspberry Pi desktop |

---

## Racer Management

### Roster Entry

Racers are entered before racing begins. Three entry paths:

1. **Manual entry** -- Type name, car number, and optionally age/grade. Optionally capture racer photo and car photo via USB camera (if connected, deferred).
2. **CSV import** -- Upload a CSV with columns for name and car number (plus optional age/grade). Import screen shows a preview and flags duplicates.
3. **Previous year's roster** -- Load from the persistent database (typically ~80% of names carry over). Operator marks returning vs. new racers, removes departed ones, and adds new entries.

### Racer Record (at entry time)

```
Racer {
    id              : int          // Internal ID, auto-assigned
    name            : string
    carNumber       : int          // May change year to year
    grade           : int?         // Age/grade -- optional; changes each year so not a stable identifier
                                   // Consider storing graduating class year and back-calculating grade for display
                                   // Or omit entirely -- not essential
    rfidCarID       : bytes?       // Assigned via RFID pairing at check-in; format TBD
    photoPath       : string?      // USB camera capture (deferred)
    carPhotoPath    : string?      // USB camera capture (deferred)
    present         : bool         // Checked in
    year            : int          // Race year
}
```

### RFID Car Pairing

RFID is read by the Start Controller and relayed SC -> FC -> RM via the BLE Car IDs characteristic (sent at staging). To pair a car to a racer name:

1. Operator opens the **Check-In** screen for a racer
2. Operator places the car on the track (or near the RFID reader on the start controller)
3. SC reads the RFID tag, sends it to FC via serial, FC notifies RM via BLE
4. RM receives the Car ID and associates it with the currently selected racer record
5. Confirmation displayed; racer is marked as checked in

> RFID is a separate major feature branch assumed to be merged before raceManager work begins. RFID car ID format is TBD -- it affects the `BLEHeatResult` struct and GATT characteristic sizing.

### Check-In

- Racers check in at the operator's station with their car
- Check-in triggers RFID pairing (above) and optional photo capture
- Absent racers remain in roster but are ineligible for bracket seeding; they can be marked as a Bye

---

## Practice Mode

Available at any time -- from the power-on menu or as a toggle during a race day.

- Race mode on the hardware is set to whichever mode the operator selects (RM writes Set Mode -> FC)
- Race results are received via BLE and displayed on-screen in real time (times, winner, reaction times)
- **No results are written to the database**
- The kiosk screen shows "PRACTICE -- Times not recorded" to avoid confusion
- Returning to a race day session resumes from where it was left off

---

## Time Trial Mode (Gate Drop)

Gate Drop mode on the hardware corresponds to Time Trial mode in the Race Manager. Heats are **rolling and not pre-scheduled** -- the operator runs cars through in any order, and the Race Manager matches results to racers by Car ID.

### Time Trial Screen Layout

The main panel shows a roster-style grid with one row per racer:

| Racer | Car # | Run 1 | Run 2 | Run 3 | Run 4 | Run 5 | Best | Last | Trend |
| --- | --- | --- | --- | --- | --- | --- | --- | --- | --- |
| Timmy | 12 | 3.412 | 3.389 | -- | -- | -- | 3.389 | 3.389 | down better |
| Johnny | 7 | 3.501 | -- | -- | -- | -- | 3.501 | 3.501 | -- |

- **Runs to use** -- configurable in settings (default = 5). Column count matches this setting.
- **Best** -- fastest time recorded for this racer across all runs
- **Last** -- most recent run time
- **Trend** -- arrow/color indicating whether last run was better (down green) or worse (up red) than their previous best

### Car Currently Racing

When the FC sends Car IDs (staging state), the two matching racer rows are **highlighted** on the time trial grid so the operator can see who is on the track.

### Full Runs

Once a racer has completed all configured runs:

- Their row changes color (e.g. gray background, muted text) to indicate they are done
- Their car ID is locked -- if FC sends a staging event with that car ID, an **error/warning** is displayed: "Car #12 (Timmy) has completed all runs"
- The operator can choose to override and allow an extra run, or dismiss the error

### Editing Times

At any time the operator can select a racer's row and edit individual run times (e.g. to remove a bad result, correct an entry). All edits are logged.

### Incomplete Runs

Racers who have not completed all configured runs are **still eligible for bracket seeding** -- they are seeded by their best available time. Missing runs are left as null in the database; no placeholder entry is required.

Before the operator transitions from Time Trial to Bracket mode, the Race Manager warns if any racers have fewer than the configured number of runs. This is a warning only -- the operator can proceed. The operator may also mark any racer as **Scratch** at this point (or at any time), which removes them from the bracket entirely.

### Places Calculation

Once all checked-in, non-scratched racers have completed their runs (or after operator manually triggers it):

- Time trial places are calculated (1st, 2nd, 3rd) by best available time
- Places are **not displayed automatically** -- they are revealed at Race Day Complete
- Calculated places are used to seed the bracket if Bracket mode follows

---

## Bracket Mode (Reaction / Pro Tree)

Reaction mode on the hardware corresponds to Bracket mode in the Race Manager. The bracket is **calculated once at the start of Bracket mode** and does not change except for byes and edits.

### Bracket Generation

1. When the operator enters Bracket mode, the Race Manager generates a single-elimination or double-elimination bracket from all checked-in, non-scratched cars
2. Bracket size is the next power of 2 at or above the car count (e.g. 18 cars -> 32-car bracket)
3. Byes fill the remaining slots and are awarded to the **top seeds** (fastest time trial times) -- the fastest cars are rewarded with a first-round bye
4. If time trial results are available (fully or partially completed), seeding is by best available time; if no time trial data exists, seeding is random or manual

**Elimination format:** Single elimination (default) or double elimination -- set in Settings.

### Bracket Screen Layout

Full-screen bracket tree:

- Current matchup **highlighted** (e.g. bright outline)
- On-deck matchup **marked** (e.g. different color)
- Completed matchups show winner name and time
- Remaining matchups show racer names
- Bye slots are labeled "BYE"

### Car ID Verification

When the FC sends Car IDs at staging, the Race Manager checks them against the scheduled matchup:

| Scenario | Action |
| --- | --- |
| Cars match current matchup | Normal -- highlight current matchup, proceed |
| Cars match on-deck matchup | Push current matchup to on-deck; new heat becomes current -- **allowed** (flexibility for out-of-order) |
| Cars match a valid future matchup (not current or on-deck) | Same as above if the matchup hasn't been run yet |
| Cars match an already-completed matchup | **Error** displayed: "This matchup was already run" |
| Cars don't match any scheduled matchup | **Warning** displayed: "Unrecognized car pairing" -- operator can proceed or abort |

### Bye / Forfeit

At any time the operator can select a racer in the bracket and mark them as a **Bye**:

- Their opponent automatically advances
- The Bye racer is noted in results but does not get a time for that matchup
- A racer who goes home early can be given a Bye for all remaining matches

### Foul Rules

| Scenario | Outcome |
| --- | --- |
| One car fouls | Fouling car is **disqualified** (DQ); opponent wins automatically; result recorded |
| Both cars foul | **Rerun** -- no result recorded; matchup returned immediately to the front of the queue as "now racing" (the on-deck matchup is not advanced); repeated until a valid result is produced |

### Manual Winner Override

The operator can select any matchup in the bracket and manually set or edit the winner -- useful for correcting sensor errors or handling edge cases.

---

## Staging Screen (Matchup Reveal)

When the FC enters `RACE_STAGING` and Car IDs are received, the Race Manager switches to a full-screen **matchup reveal**:

```
┌─────────────────────────────────────────────┐
│                                             │
│   [Car Photo: Timmy's car]                  │
│         TIMMY                               │
│          vs.                                │
│         JOHNNY                              │
│   [Car Photo: Johnny's car]                 │
│                                             │
│        LEFT LANE      RIGHT LANE            │
└─────────────────────────────────────────────┘
```

- Shows racer names in large text
- Shows car photos if available (from check-in)
- Identifies left vs. right lane assignment
- Remains on screen until FC transitions to `RACE_COUNTDOWN` or `RACE_RACING`

---

## Race Day Complete

When the operator selects **Race Day Complete**:

1. The application calculates final results:
   - **Time Trial:** 1st, 2nd, 3rd place by best time
   - **Bracket:** Winner, runner-up (and 3rd/4th if double elimination)
   - **Best Reaction Time:** Fastest single reaction time of the night (event-wide minimum across all racers' personal best reaction times). Consolation award -- displayed alongside each racer's best and average reaction time so kids can compare.
2. A **celebration reveal screen** is shown -- operator-controlled, screen advances manually to reveal each award (builds suspense)
3. Optionally, the operator enters the **Best in Show** award winner(s) and places (judged separately before closing)
4. All results are saved to the persistent database (see [Persistent Database](#persistent-database))

### Best in Show

- Separate judged award for car design, creativity, craftsmanship, humor, or other subjective qualities -- entirely independent of race results
- Judged by an external panel designated by the organizer (not the Race Manager operator)
- Configurable divisions per event: zero, one, or two age-based divisions (typical split: Younger 3rd-5th grade, Older 6th-8th grade). All cars race together regardless of division.
- Up to 3 places per division; 2nd and 3rd are optional -- operator leaves blank if not awarded
- Operator enters winner names manually after judging, before closing the session
- Saved to database alongside race results

---

## UI State Machine

The Race Manager enables and disables UI elements based on the current `raceState` received from the FC. The RM tracks the last-known state from BLE notifications.

| State | RM UI Behavior |
| --- | --- |
| `RACE_IDLE` | "Set Mode" button active; roster and settings editable; heats can be manually adjusted |
| `RACE_STAGING` | Show Staging/Matchup Reveal screen; highlight current racers in time trial grid; no editing |
| `RACE_COUNTDOWN` | Show countdown indicator; disable all editing; lock current matchup display |
| `RACE_RACING` | Show "Racing..." indicator; disable all editing |
| `RACE_COMPLETE` | Receive Heat Result via BLE; update time trial grid or bracket; enable error-correction actions (Discard, Re-run, Skip) |
| BLE disconnected | Show connection warning banner; disable all BLE-dependent actions; time trial grid goes read-only |

---

## Deferred Features / Backlog

The following are intentionally out of scope for the initial raceManager release. They are documented here to capture intent and avoid re-discussing them from scratch.

### Double Elimination

Support a losers-bracket in addition to the winners bracket. Adds significant bracket-state complexity. Default will remain single elimination.

### Lane Bias Analysis

Post-event analytics to detect whether one lane has an inherent speed advantage.

**Methodology:**

- **Track-level bias:** Average all left-lane times across all heats; average all right-lane times across all heats; report the difference.
- **Per-racer bias:** For each racer who ran both lanes, average their left-lane times and average their right-lane times; report the per-racer delta. This separates car performance from lane advantage.

**Correction options (also deferred, decision TBD):**

- Equal runs per car -- scheduling constraint ensuring each car runs each lane the same number of times (no time modification)
- Correction factor -- apply a lane-bias offset to raw times before calculating standings (more powerful, needs a defensible methodology)

### Dial-In Mode

Gate Drop timing used to calculate a speed handicap per racer. `MODE_DIALIIN` is defined in `raceTypes.h` and is fully supported by both controllers -- it is intentionally not reachable via the mode button because the handicap calculation requires historical run data that only the Race Manager holds. The RM activates it by writing the Set Mode BLE characteristic when the system is idle.

> **Mechanic TBD -- research required.** Two candidate approaches: (a) adjust race results mathematically by each car's handicap after the heat; (b) adjust the countdown light timing per lane so slower cars get an earlier GO signal (requires hardware support for per-lane countdown delay). Real drag strip "dial-in" conventions should be reviewed before committing to either approach. This feature was suggested by a participant and is intentionally vague until researched.

### USB Camera

A USB camera connected to the RPi (not practical on the Arduino) would enable:

- **Check-in photos:** Racer photo and car photo captured at check-in
- **Slow-motion replay:** Ring-buffer video capture during racing; replay last 1-2 seconds in slow motion after `RACE_COMPLETE`

### Test Mode (from Race Manager)

RM-initiated hardware test: send Initiate Test to FC when `RACE_IDLE`, display test results on-screen. The `RACE_TEST` self-test itself is implemented in firmware; what remains TBD is the BLE Initiate Test / Test Result characteristic design.

---

## Error Handling

Operator-side corrections available after a heat completes (during `RACE_COMPLETE` state on FC):

| Action | Description |
| --- | --- |
| **Discard / Erase time** | Mark one or both lane results as void; exclude from standings; car's run slot is freed for re-use |
| **Re-run race** | Flag the heat for re-run; re-insert as the next scheduled heat |
| **Skip heat** | Remove the heat from the schedule without re-running (e.g. car scratched mid-event) |
| **Edit time** | Manually override a specific run time in the time trial grid |
| **Set winner** | Manually set bracket matchup winner (overrides sensor result) |

These are Race Manager UI actions only -- no signals are sent to the Arduino controllers.

---

## Export

At any time after heats are run (and required after Race Day Complete):

- **CSV export** -- all heat results, per-racer times, standings, reaction times
- **PDF export** (stretch) -- formatted results sheet suitable for printing and posting
- Export includes: racer name, car number, all run times, best time, time trial place, bracket result, best reaction time, average reaction time, foul count

---

## Persistent Database

Results are saved locally on the RPi (SQLite is a natural fit). The database persists across sessions and years.

### Racer Record (persistent)

```
Racer {
    id              : int
    name            : string
    carNumber       : int          // May change year to year; stored per season result
    grade           : int?         // Optional; see note in Racer Record above
    photoPath       : string?      // Deferred
    carPhotoPath    : string?      // Deferred
}
```

### Season Record (per year)

```
SeasonResult {
    racerID         : int          // FK -> Racer
    year            : int
    bestTimeTrial   : us?          // Best time trial time
    timeTrialPlace  : int?         // 1st, 2nd, 3rd, etc.
    bracketPlace    : int?         // 1 = winner, 2 = runner-up, etc.
    bestReactTime   : us?          // Fastest single reaction time across all bracket heats
    avgReactTime    : us?          // Average reaction time across all bracket heats
    bestInShowPlace : int?         // If awarded
}
```

### Heat Record

```
HeatResult {
    id              : int
    year            : int
    mode            : enum (TimeTrial, Bracket, Practice)
    heatSeq         : int          // Heat number within the event
    leftRacerID     : int?         // FK -> Racer; null if car ID not matched
    rightRacerID    : int?
    leftCarTime     : us
    rightCarTime    : us
    leftReactTime   : us?          // null in GATEDROP mode
    rightReactTime  : us?
    leftFoul        : bool
    rightFoul       : bool
    winner          : enum (Left, Right, Tie, Void, Rerun)
    notes           : string?      // Operator edit notes
}
```

---

## Settings

Configurable per event (stored with the session, not globally):

| Setting | Default | Description |
| --- | --- | --- |
| Time trial runs per car | 5 | How many Gate Drop runs are recorded per car  |
| Best in Show divisions  | 1 | 0 none, 1 single, 2 Younger/Older age groups  |

---

## Implementation Phases

### Phase 1 -- BLE Foundation (Firmware, prerequisite)

- [ ] Define GATT service UUID and characteristic UUIDs in `finishController.cpp`
- [ ] Implement `notifyBLEState()`, `notifyBLECarIDs()`, `notifyBLEResult()`, heartbeat at placeholder sites
- [ ] Implement writable characteristics: Set Mode and Initiate Test; guard with `RACE_IDLE` check
- [ ] BLE connection event handler; `bleConnected` flag
- [ ] Validate BLE notify timing does not interfere with display ISR (30 us settle)

### Phase 2 -- Race Manager Skeleton (RPi)

- [ ] Decide application framework (see OQ-RM1)
- [ ] Implement BLE central via Python `bleak`; connect by service UUID; subscribe to all notifies
- [ ] Kiosk auto-launch at boot (systemd service or autostart)
- [ ] Power-on menu: Continue / New Race / Practice / Test / Quit to OS
- [ ] Log raw BLE events to console -- validate full data path end-to-end

### Phase 3 -- Roster and Time Trial

- [ ] Racer entry: manual, CSV import, previous year import from database
- [ ] RFID pairing workflow at check-in (prerequisite: RFID firmware branch merged)
- [ ] Settings UI (runs per car)
- [ ] Time trial grid: runs, best, last, trend, color for completed rows
- [ ] Car ID -> racer row highlighting during staging
- [ ] Full-runs error/warning when car ID is already complete
- [ ] Time trial places calculation (hidden until reveal)

### Phase 4 -- Bracket and Staging Screen

- [ ] Bracket generation (single elimination, seeded from time trial if available)
- [ ] Bracket screen: tree display, current/on-deck markings
- [ ] Car ID verification against scheduled matchup; out-of-order flexibility
- [ ] Staging / matchup reveal screen (full-screen with names and car photos)
- [ ] Bye / forfeit handling
- [ ] Foul logic (DQ, re-race on double foul)
- [ ] Manual winner override

### Phase 5 -- Race Day Complete and Database

- [ ] Race Day Complete flow: standings calculation, celebration reveal screen
- [ ] Best in Show entry
- [ ] Persistent SQLite database: season records, heat history, multi-year racer records
- [ ] Previous year roster import from database
- [ ] Export to CSV
- [ ] Practice mode toggle from within a race day session
- [ ] PDF export (stretch)

---

## Open Questions

| # | Question | Why it matters |
| --- | --- | --- |
| OQ-RM1 | What application framework? Needs research -- no decision made. | Drives all of Phase 2 architecture; must be resolved before coding begins |
| OQ-RM2 | RFID car ID format -- single byte, multi-byte UID, other? | Affects `BLEHeatResult` struct and GATT characteristic sizing; resolved when RFID branch is designed |
| OQ-RM3 | Grade/age field: store graduating class and back-calculate, store raw grade, or omit entirely? | Low urgency; doesn't affect race logic |
| OQ-RM4 | BLE payload: how to signal reaction time "not applicable"? Candidates: (a) `reactionValidMask` byte matching firmware pattern; (b) infer from `foulMask` + mode -- no extra field needed; (c) decide when designing the GATT layer. Defer to Phase 1. | Affects `BLEHeatResult` struct size and Race Manager parsing logic |
| OQ-RM5 | Schema: should the `Racer` record be split into a persistent `Person` (name, lifetime records) and an annual `Car` (carNumber, rfidCarID, year)? Current schema conflates both. A racer has a different car each year; car is the annual entity, racer is the persistent one. Low urgency -- resolve when beginning database design in Phase 5. | Affects foreign key structure in `HeatResult` and `SeasonResult`; name display throughout UI |

---

## Dependencies and Blockers

| Item | Status | Blocks |
| --- | --- | --- |
| BLE GATT service defined on FC | Not started | All of Phase 1 and everything after |
| Application framework decision (OQ-RM1) | Needs research | All of Phase 2 |
| RFID firmware branch | Not started -- own branch | RFID pairing at check-in; Car ID verification in bracket; assumed merged before raceManager branch |
| Reaction-time "not applicable" sentinel fixed in firmware | Not started | Correct reaction time in BLE payload |

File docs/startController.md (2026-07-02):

# Derby Track Start Controller System

> As-built design reference. The firmware in `firmware/startController/src/` is
> authoritative; this document explains the design and the reasoning behind it.

### System Overview

The Start Controller manages the beginning of pinewood derby races, controlling starting gates and countdown lights. It operates as an embedded system on an Arduino Nano (ATmega328P) with a custom PCB shield, communicating with a separate Finish Controller via serial UART.

### Core Capabilities

#### Race Management

* **Four Race Modes**: Gate Drop, Reaction Time, Pro Tree, and Dial-In. The first three cycle via the mode button. Dial-In is only activated by a BLE command from the Race Manager -- it requires historical run data to compute handicaps, which is beyond the scope of the standalone controllers.
* **Six Race States**: Idle -> Staging -> Countdown -> Racing -> Complete -> (back to Idle); Test state (RACE_TEST) runs a 4-phase self-test: FC communication ping, light chase, gate cycle, and interactive button verification
* **Automated Sequencing**: Handles complete race lifecycle with state-driven logic

#### Hardware Control
* **Dual Starting Gates**: Electromagnet-held gates with spring-loaded drop mechanism
* **Return Solenoid**: Automated gate reset system with 500 ms activation window
* **Christmas Tree Lights**: Dual 6-light arrays (Blue, Yellowx3, Green, Red) via 74HC595 shift register

#### User Interface

* **Four Button Inputs**: Start (A6), Mode (A7), Left Lane (D18), Right Lane (D19) -- all hardware-debounced via Schmitt triggers on the PCB shield; no software debounce required
* **Visual Feedback**: LED patterns indicate mode, state, and race status
* **Foul Detection**: Red light indication for false starts in reaction modes

### Technical Architecture

#### Module Structure
| Module | Purpose | Key Functions |
|---|---|---|
| **startController** | Main state machine and orchestration | `startControllerSetup()`, `startControllerLoop()`, state transitions |
| **serialComm** | UART communication protocol | `rxSerial()`, `txRaceState()`, ACK/NACK handling |
| **lights** | LED tree control via 74HC595 shift register | `updateLights()`, `buildLightConfig()`, `startBlink()`, `updateBlink()` |
| **gates** | Electromagnet and solenoid control | `dropGate()`, `returnGates()` |
| **buttons** | Input debouncing and detection | `isStartPressed()`, `isModePressed()`, `isLeftPressed()`, `isRightPressed()` |
| **globals** | Shared enumerations and constants | Race states, modes, bitmasks |

#### Communication Protocol

##### Message Types (12 total):
* State synchronization (MSG_RACE_MODE, MSG_RACE_STATE)
* Race events (MSG_RACE_START, MSG_LEFT_REACT, MSG_RIGHT_REACT, MSG_FOUL, MSG_WINNER, MSG_DISP_ADVANCE)
* Control flow (MSG_ACK, MSG_NACK, MSG_ERROR)
* Null placeholder (MSG_NULL)

##### Reliability Features:
* ACK/NACK confirmation system
* 3-retry limit with 50 ms timeout per retry
* State verification before transitions

#### State Machine Design
```
IDLE ──[Start]──> STAGING ──[Start]──> COUNTDOWN ──[GO]──> RACING ──[Complete]──> COMPLETE
 ^                   |                                                                 |
 └───────[Mode]──────┘                                              [Start/Display]───┘
 ^
 └──── TEST (4-phase self-test; hold MODE at power-up to enter)
```

##### State Characteristics:
* Entry actions (reset, initialization)
* Continuous actions (monitoring, updates)
* Exit actions (cleanup, transmission)
* Guarded transitions via allowed-transition table (same 6x6 table in both controllers)

#### Mode Machine Design

Modes cycle via the Mode button (IDLE state only): Gate Drop -> Reaction -> Pro -> Gate Drop. Each transition blinks the corresponding yellow light 3x. Dial-In is the fourth mode but is not reachable through the button -- it is only activated by the Race Manager via BLE. Once active, pressing the mode button returns to Gate Drop.

| Mode | Light Pattern | Countdown Delay | How Entered |
|---|---|---|---|
| Gate Drop | Y1 | 500 ms per stage | Mode button |
| Reaction | Y2 | 500 ms per stage | Mode button |
| Pro Tree | Y3 | 400 ms per stage | Mode button |
| Dial-In | GO | 500 ms per stage | BLE from Race Manager only |

### Key Design Decisions

#### 1. Modular Architecture
Each hardware subsystem has its own module with clear interfaces, enabling independent testing and modification.

#### 2. Pragmatic Global State
Uses a `SerialRxState rx` struct (extern from serialComm) for inter-module state visibility, appropriate for embedded systems. Local state and timing data are kept in file-local structs inside each controller source file.

#### 3. Hybrid Programming Style
Combines procedural functions with data structs (`stateMachine`, `modeSelect`, `CountDownCtx`), avoiding over-engineering while maintaining structure.

#### 4. Timing Precision
* Microsecond precision (`micros()`) for reaction time measurement and gate-trigger timestamps
* Millisecond precision (`millis()`) for countdown stage delays and UI timeouts

#### 5. Safety First
* Hardware timeouts on all actuators
* Foul detection in reaction modes (early gate trigger records foul flag and drops gate immediately)
* State transition gating (selfTransition requires ACK before committing)

### Performance Characteristics

| Metric | Value | Notes |
|---|---|---|
| **Serial Baud** | 115,200 | High-speed UART |
| **Reaction Precision** | +/-1 us | Using micros() |
| **Message Timeout** | 50 ms | Per-retry; 3 retries max |
| **Countdown Stage Delay** | 400 ms (Pro) / 500 ms (others) | Between each yellow light |

### Countdown Sequence Detail

On entry to RACE_COUNTDOWN the countdown state machine begins:

* **Gate Drop / Reaction / Dial-In**: CD_STAGED -> CD_Y3 -> CD_Y2 -> CD_Y1 -> CD_GO (500 ms per stage)
* **Pro Tree**: CD_STAGED -> CD_Y1 -> CD_GO (400 ms, one stage -- single yellow flash)

At CD_GO, gates drop (Gate Drop mode) or stay armed (Reaction/Pro modes), `raceStartUs` is captured, and MSG_RACE_START is sent to the finish controller. The state machine transitions to RACE_RACING.

### Reaction Time & Foul Handling

In Reaction/Pro/Dial-In modes, the Left and Right Lane buttons act as car-release triggers:

* **During COUNTDOWN**: A button press before CD_GO is an early start -> gate drops, foul flag set, `carStartUs` recorded.
* **During RACING**: A button press after GO -> gate drops, `carStartUs` recorded, reaction time calculated.

Reaction time = `|raceStartUs - carStartUs|` (absolute difference; stored as unsigned microseconds). A foul reaction time is *added* to race time at the finish controller; a clean reaction time is *subtracted*.

Pending messages (foul status, left reaction, right reaction) are sent one at a time over serial before the state machine accepts a RACE_COMPLETE transition from the finish controller.

### Deployment Notes

#### Hardware Requirements
* Arduino Nano (ATmega328P)
* Custom PCB shield (see KiCad schematics in hardware/startBoard/)
* External 5V regulator for electromagnets and logic
* 74HC595 shift register for lights (D2 data, D3 clock, D5 latch)
* Gate pins: D4 (left electromagnet), D7 (right electromagnet), D6 (return solenoid)

#### Pin Assignments
| Function | Pin |
|---|-----|
| Start button | A6 (analog, active <=512) |
| Mode button | A7 (analog, active <=512) |
| Left Lane button | D18 (digital, active LOW, external pull-up) |
| Right Lane button | D19 (digital, active LOW, external pull-up) |
| Lights shift-register data | D2 |
| Lights shift-register clock | D3 |
| Lights shift-register latch | D5 |
| Left gate electromagnet | D4 |
| Right gate electromagnet | D7 |
| Return solenoid | D6 |

#### Power Considerations
* 12V supply for electromagnets
* 5V logic with external regulation
* ~1A peak current during gate return

### Maintenance Guidelines

#### Adding Race Modes
1. Extend `raceMode` enum in `raceTypes.h`
2. If the mode should be reachable via the mode button, add it to `nextMode()` in `modeMachine` (startController.cpp). Modes only reachable via BLE (like Dial-In) are intentionally omitted from `nextMode()` but still need the `DIALIIN -> GATEDROP` exit case so the operator can leave the mode via button.
3. Define light pattern in both `selfTransition()` and `rxTransition()` of `modeMachine`
4. Add countdown delay case in `CountDownCtx::tick()` if different from 500 ms

#### Debugging
* Serial output at 115,200 baud
* LED patterns indicate mode and state
* `"future:"` comments in source mark planned features
* State visibility through `stm.current` and `md.current` locals

#### Testing
See [testing.md](testing.md) for the layered test strategy (static analysis
through on-hardware self-test) and
[bench-test-protocol.md](bench-test-protocol.md) for the two-board bring-up
procedure.

### Summary
The Start Controller implements a state-driven embedded system with modular hardware abstraction, a coordinated serial protocol, and microsecond-precision reaction timing. Its clear state and mode machines make it straightforward to extend with new modes or features while the ACK/NACK serial protocol ensures the finish controller stays in sync.

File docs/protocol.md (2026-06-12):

# DerbyTimer UART Wire Protocol

Byte-level reference for the Start Controller (SC) <-> Finish Controller (FC)
serial protocol. A third party (e.g. the Raspberry Pi Race Manager) should be
able to implement a compatible endpoint from this document alone. The
authoritative implementation is `firmware/lib/shared/serialComm.h/.cpp`.

## Transport

| Property | Value |
| --- | --- |
| Physical | UART, 115200 baud, 8N1 (`serialBaud` in serialComm.h) |
| SC port | `Serial` (only UART on the ATmega328P) |
| FC port | `Serial1` (D0/D1 on the Nano 33 BLE); USB `Serial` is reserved for debug |
| Framing | None -- messages are a bare ID byte followed by a fixed-length payload |
| Integrity | None (no checksum/CRC) -- see "Known limitations" |

## Message format

```
[ ID (1 byte) ][ payload (0-4 bytes, length fixed per ID) ]
```

Payload lengths are defined in `getExpectedPayloadLength()`. Multi-byte
payloads are **little-endian** (both MCUs are little-endian; `memcpy` on the
wire struct).

## Message table

| ID | Name | Payload | Direction | Meaning |
| --- | --- | --- | --- | --- |
| 0 | MSG_NULL | -- | -- | Placeholder, never sent |
| 1 | MSG_ACK | 1: acked msg ID | both | Acknowledge receipt of the named message |
| 2 | MSG_NACK | 1: nacked msg ID | both | Reject the named message (bad value / not allowed); sender retries |
| 3 | MSG_RACE_MODE | 1: raceMode | SC -> FC | Mode change (GATEDROP=0, REACTION=1, PRO=2, DIALIIN=3) |
| 4 | MSG_RACE_STATE | 1: raceState | both | State transition by the initiating controller (see coordination) |
| 5 | MSG_RACE_START | 0 | SC -> FC | GO fired -- FC stamps `micros()` on receipt and arms sensors |
| 6 | MSG_ERROR | 1: errCode | both | SC->FC: critical, FC aborts to IDLE. FC->SC: informational only (ADR-0004) |
| 7 | MSG_LEFT_REACT | 4: uint32 us | SC -> FC | Left lane reaction time in microseconds |
| 8 | MSG_RIGHT_REACT | 4: uint32 us | SC -> FC | Right lane reaction time in microseconds |
| 9 | MSG_FOUL | 1: bitmask | SC -> FC | bit0 = left foul, bit1 = right foul (sent at RACING entry) |
| 10 | MSG_WINNER | 1: bitmask | FC -> SC | bit0 leftWin, bit1 rightWin, bit2 tie, bit3 noResult |
| 11 | MSG_DISP_ADVANCE | 0 | SC -> FC | Operator pressed Start in COMPLETE: advance the display |

`MSG_COUNT` (12) is a sentinel; receivers discard any ID >= 12 silently
(likely line noise -- NACKing garbage would flood the wire).

## ACK / retry discipline

- Every queued message expects an `MSG_ACK` carrying its ID. ACK/NACK
  themselves are fire-and-forget (never ACKed).
- The receiver ACKs **immediately on parse**, before acting on the content.
  A semantically rejected value (e.g. disallowed state transition) gets a
  follow-up NACK from the application layer.
- Sender side: one message in flight at a time, FIFO queue, one slot per
  message ID (re-enqueueing a queued ID is a no-op). `MSG_RACE_START` is
  priority and jumps to the front of the queue.
- Timeout: no ACK within **50 ms** (`txTimeout`) -> TX_TIMEOUT (terminal, no
  resend by the engine; callers decide). NACK -> retry, up to **4 total
  transmission attempts** (`maxRetries` = 3 retries after the initial send),
  then TX_FAILED.
- Payloads are captured at enqueue time, so the wire always carries the value
  current when the event happened.

## RX validation

- Reaction times outside `0..maxValidReactionUs` (10 s) are NACKed and
  discarded.
- A partial message (ID seen, payload incomplete) is left in the buffer; if it
  does not complete within `stalePartialTimeoutMs` (100 ms) the ID byte is
  flushed and NACKed so the sender's retry can resync the stream.

## State coordination model

Both controllers run the same `stateMachine` (stateMachine.h) with one
initiator per transition; the follower commits on `MSG_RACE_STATE` receipt
(edge-triggered via the `rx.StateChanged` flag -- never re-process a stale
`rx.State` value):

| Transition | Initiator |
| --- | --- |
| IDLE -> STAGING, STAGING -> IDLE, STAGING -> COUNTDOWN, COUNTDOWN -> RACING | SC |
| RACING -> COMPLETE, COMPLETE -> IDLE | FC |
| any -> IDLE (abort via `forceIdle()`, best-effort MSG_RACE_STATE(IDLE)) | either |

## Typical heat (REACTION mode)

```
SC: MSG_RACE_STATE(STAGING)      -> FC: ACK
SC: MSG_RACE_STATE(COUNTDOWN)    -> FC: ACK
SC: MSG_RACE_START               -> FC: ACK   (FC stamps t0, arms sensors)
SC: MSG_RACE_STATE(RACING)       -> FC: ACK
SC: MSG_FOUL(mask)               -> FC: ACK   (at RACING entry; includes early starts)
SC: MSG_LEFT_REACT(us)           -> FC: ACK   (at car release, or RACING entry if fouled)
SC: MSG_RIGHT_REACT(us)          -> FC: ACK
FC: MSG_RACE_STATE(COMPLETE)     -> SC: ACK   (both lanes finished or DNF)
FC: MSG_WINNER(mask)             -> SC: ACK
SC: MSG_DISP_ADVANCE             -> FC: ACK   (show reaction times)
SC: MSG_DISP_ADVANCE             -> FC: ACK   (done)
FC: MSG_RACE_STATE(IDLE)         -> SC: ACK
```

## Timing model notes

- FC's race clock t0 is stamped when `MSG_RACE_START` is parsed, not when the
  gate physically drops: UART (2 bytes at 115200 ~ 174 us) plus one loop
  iteration of latency. The offset is common to both lanes, so winner
  determination is unaffected; absolute times carry a small constant bias.
- Reaction times are measured on the SC (gate drop to car release) and carry
  no transport latency.

## Known limitations / planned evolution

- **No framing or checksum**: a corrupted byte can desync the stream until the
  stale-partial flush recovers it; a corrupted payload byte that stays in
  range is undetectable. Deferred decision (2026-06): add `[SOF][len][CRC-8]`
  framing plus a version handshake on the feature-raceManager branch, before
  any third endpoint joins the wire.
- **Extending the protocol**: adding a new message ID is backward-safe (old
  firmware discards unknown IDs). Changing an existing payload length is NOT
  -- old receivers will misparse the stream. Always allocate a new ID instead.

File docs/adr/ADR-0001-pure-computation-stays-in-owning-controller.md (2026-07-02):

# ADR-0001: Pure computation stays in its owning controller file

**Status:** Accepted  
**Date:** 2026-05-21

## Context

The finishController firmware separates concerns across files that map to hardware interfaces:
- `sensors.cpp` -- ISR and optical sensor hardware
- `display.cpp` -- BCD decoder and 7-segment display hardware
- `finishController.cpp` -- state machine and race logic

During the `computeHeatResults()` refactor, the question arose whether a pure computation function (no hardware dependencies, no ISR, no Serial) deserves its own file to maximise testability -- it could be compiled and exercised on a PC without any Arduino toolchain.

## Decision

Pure computation stays in `finishController.cpp`, the controller file that owns the domain logic it serves.

File boundaries in this project map to hardware interfaces, not abstraction layers. A new file implies a new hardware concern. A pure function that is only ever called from one controller file does not warrant a new file boundary just because it happens to be hardware-free.

If a future PC-side test harness is built, the extraction can happen at that point with a real consumer to justify the seam.

## Consequences

- `computeHeatResults()` and its associated types (`HeatLaneResult`, `HeatResults`) live in `finishController.cpp` as file-static.
- Future architecture reviews should not re-suggest extracting pure computation into its own file unless a second concrete consumer (e.g., a test harness or a shared library) exists to justify the seam.
- The rule to remember: **one adapter = hypothetical seam; two adapters = real seam.**

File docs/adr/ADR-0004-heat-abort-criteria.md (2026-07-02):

# ADR-0004: Heat abort criteria and forceIdle semantics

**Status:** Accepted
**Date:** 2026-05-26

## Context

Two controllers coordinate over UART to run a heat. Either controller can detect a failure that makes the heat result invalid -- a missed serial message, a sensor failure, or a timeout. The system needs a clear, documented rule for *when* to abort a heat versus when to continue with degraded data.

The `forceIdle()` mechanism lets either controller immediately reset to IDLE and fire a best-effort `MSG_RACE_STATE(IDLE)` so the peer can follow. It replaced the earlier "halt and blink" behavior, which required a power cycle to recover.

## Decision

**Abort a heat (call `forceIdle()`) only when the result would be untrustworthy and the heat must be re-run.**

A result is untrustworthy when a required data dependency was permanently lost -- not merely delayed or imprecise.

### Current abort triggers

| Trigger | Controller | Condition | Rationale |
|---|---|---|---|
| `MSG_RACE_START` TX failure | SC | `TX_TIMEOUT` or `TX_FAILED` | FC sensors never armed. No finish times can be captured. Heat is structurally impossible to complete. |
| `MSG_FOUL` TX failure | SC | `TX_TIMEOUT` or `TX_FAILED` | FC does not know foul state. In REACTION/PRO modes, foul determines the carTime formula; a wrong foul flag produces a wrong result. |
| `MSG_ERROR` received | FC | `rx.lastErrorCode != err_NULL` | SC has already aborted and notified FC. FC follows to stay in sync. |
| Countdown SC-silent timeout | FC | 10 s elapse in COUNTDOWN with no `MSG_RACE_START` | SC appears dead or desynchronized. Sensors were never armed. No meaningful race can proceed. |

### Soft-failure paths (no abort)

| Event | Controller | Rationale |
|---|---|---|
| `MSG_LEFT_REACT` / `MSG_RIGHT_REACT` TX failure | SC | Reaction times are record-keeping only. FC's missing-reaction guard fires a best-effort `txError` warning before displaying best-effort times (equal to race times). The heat result, while imprecise, is still valid and displayable. |
| `MSG_DISP_ADVANCE` TX failure | SC | Display advance is operator convenience only; operator can press Start again. |
| `MSG_WINNER` TX failure | FC | Finish times are already on the FC display. SC retries once then shows no win lights; the heat result is preserved on the FC side. |

### MSG_ERROR convention

`MSG_ERROR` is an abort notification, not a general-purpose warning channel. When SC calls `txError()` before `forceIdle()`, it serves as a best-effort "I am aborting" signal to FC. FC that receives `MSG_ERROR` calls `forceIdle()` to stay in sync.

**Asymmetry:** SC does **not** forceIdle on `rx.lastErrorCode`. This is intentional -- FC currently only sends `MSG_ERROR` as the missing-reaction-time warning, which is informational and does not require SC to abort. No current FC code path sends `MSG_ERROR` as a halt signal. If that changes in the future, the convention must be updated here and the SC loop must add a `lastErrorCode` check.

### Known over-conservatism: MSG_FOUL in GATEDROP mode

In `MODE_GATEDROP`, no reaction-time buttons are polled during COUNTDOWN or RACING, so `laneStartUs[]` is never set and `isFoul()` always returns false. The `MSG_FOUL` payload is always `0b00`. A `MSG_FOUL` TX failure in GATEDROP mode aborts a heat whose result would have been correct even without the message -- because FC defaults to no-foul when no foul message is received, matching the always-zero payload.

This over-conservatism is accepted for v1.0. A future refinement could suppress the abort when mode is GATEDROP and foul mask is zero, but the added complexity is not justified for the rare TX-failure scenario.

## Future: Race Manager integration

When the Race Manager (BLE, feature-raceManager branch) is implemented, every `forceIdle()` call should also trigger a BLE notification to the Race Manager so it can mark the heat as incomplete in the bracket. The integration point is inside `stateMachine::forceIdle()` or at the FC's `rx.lastErrorCode` handler.

## Consequences

- Any new abort condition must be evaluated against the "untrustworthy result" criterion before adding a `forceIdle()` call.
- `MSG_ERROR` must not be used as a soft-warning channel if the receiver calls `forceIdle()` on all errors. Either differentiate severity levels or keep `MSG_ERROR` = abort signal.
- The `criticalTxError` variable in both controllers is dead code left over from before this abort design was established. It should be removed (tracked in the project backlog).

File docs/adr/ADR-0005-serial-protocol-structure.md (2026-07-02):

# ADR-0005: Serial protocol structure

**Status:** Accepted
**Date:** 2026-05-21

## Context

The two controllers communicate over a single UART at 115200 baud. Several structural decisions were made during initial development that are not otherwise visible in the code.

## Decisions

### Message framing

Every message is a 1-byte message ID followed by a fixed-length payload. Payload length is implied by the message type -- there is no length prefix, no checksum, and no end-of-frame marker. The receiver calls `getExpectedPayloadLength()` to know how many bytes to wait for before processing.

Rationale: the message set is small, statically defined, and both ends share the same compiled enum. A dynamic length field or checksum would add complexity with no practical gain given the controlled environment (direct UART, no routing).

### ACK/NACK are immediate fire-and-forget

`txAck()` and `txNack()` write bytes directly to Serial and return. They are never queued. Any message that is not MSG_ACK or MSG_NACK expects exactly one ACK from the receiver.

Rationale: ACK/NACK are responses, not initiators. Queuing them would introduce ordering problems -- the receiver has already committed the message and is waiting; any delay in the ACK risks a spurious timeout and retry on the sender side.

### Baud rate: 115200

The baud rate was chosen to keep MSG_RACE_START latency within the timing budget of the race start signal. At 115200 baud a 2-byte message takes ~175 us on the wire; a full ACK round trip is under 500 us. Slower baud rates were ruled out because MSG_RACE_START triggers the finish controller's race clock -- any wire delay adds directly to timing error.

### serialComm.h does not include raceTypes.h for race state/mode values

`rxSerial()` populates `rx.State` and `rx.Mode` as raw `uint8_t`. Callers cast to `raceState`/`raceMode` from `raceTypes.h`. This keeps serialComm independent of the race domain model -- it is a transport layer, not a domain layer.

Exception: `Lane` (from `raceTypes.h`) is used in the `txReactionTime()` signature because it is a hardware-addressing type, not an interpreted domain value, and using it prevents the left/right swap bug that arises with a raw bool.

## Consequences

- Adding a new message requires updating `serialMsgID`, `getExpectedPayloadLength()`, the RX switch, and a new `tx*()` function. No framing or length-prefix code needs to change.
- The "no checksum" choice means a corrupted byte causes a NACK or a parse error; the retry mechanism handles recovery. Persistent corruption triggers `criticalTxError`.
- Future high-throughput use cases (e.g. streaming sensor data) would require revisiting the protocol -- the current design assumes a small, event-driven message set.

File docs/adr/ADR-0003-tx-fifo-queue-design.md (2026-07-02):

# ADR-0003: TX FIFO queue with single in-flight message

**Status:** Accepted
**Date:** 2026-05-21

## Context

The original TX design duplicated the send/retry/timeout state machine identically inside every `tx*()` function (~7 copies). This created a copy-paste maintenance burden and made retry policy changes a 7-site edit. It also allowed multiple messages to be "in flight" simultaneously (each had independent state), which was hard to reason about.

## Decision

A FIFO queue inside `serialComm.cpp` serializes all outgoing messages: one message is sent at a time, and the next message is not attempted until the current one reaches a terminal status (TX_ACKED, TX_TIMEOUT, or TX_FAILED). The retry state machine is implemented once in the private `txDrive()` function.

### Public API contract

**Enqueueing:** Each `tx*()` function returns `bool`:
- `true` -- message was newly enqueued (slot was idle or in a terminal state)
- `false` -- message was not enqueued (already in flight TX_SENT, or already waiting in queue)

The bool return allows callers to detect a duplicate enqueue attempt. Callers that don't care about the outcome can ignore the return value.

**Querying:** `txStatusOf(serialMsgID id)` returns the current status of any message slot. Callers poll this each loop to detect terminal status and act accordingly (commit a state change, flag an error, etc.).

**Driving:** `txService()` must be called once per main loop to advance the queue. It sends the front-of-queue message on first call, tracks the timeout window on subsequent calls, and dequeues on terminal status.

**Reset:** `resetTxState()` is internal. A new enqueue automatically resets the tracker slot -- callers never call it directly.

### Priority

MSG_RACE_START is the only priority message. When enqueued, it jumps to the front of the queue. This guarantees minimal latency for the race start signal regardless of what else is queued. No other message has priority status -- MSG_RACE_STATE transitions occur on human timescales where queue position is irrelevant.

### Retry policy

- NACK triggers an automatic retry (up to `maxRetries = 3`), then TX_FAILED.
- Timeout (no ACK within `txTimeout = 50 ms`) -> TX_TIMEOUT (terminal, no automatic retry).
- Callers that want to retry after a timeout must re-enqueue the message explicitly.

### Payload capture

Payload bytes are captured into `TxTracker.payload[4]` at enqueue time. The public `tx*()` wrappers own payload construction (type casting, bitmask building, memcpy). `txDrive()` reads the captured bytes and calls `sendMessage()` -- it has no knowledge of message semantics.

## Consequences

- Adding a new message type requires only a new `tx*()` wrapper (3-5 lines) plus entries in the message ID enum and `getExpectedPayloadLength()`. The retry engine needs no changes.
- The single-in-flight constraint means a stuck message (e.g. repeated NACKs) blocks the queue until it reaches TX_FAILED. The `criticalTxError` path in both controllers handles this for messages where failure is unrecoverable.
- Maximum payload size is 4 bytes (`sizeof(uint32_t)`). If a future message requires a larger payload, `TxTracker.payload` must be widened -- this is an internal change only.
- The RFID UID message (planned) will use a longer payload; if the UID exceeds 4 bytes the payload field must be widened before that message is added.

## Amendment (2026-07): txResend()

`txResend(id)` re-enqueues a message from the payload bytes captured in its tracker slot at the original enqueue -- the payload-capture mechanism above is what makes a resend possible without the caller rebuilding (or retaining) the payload. It is permitted only from the failure statuses (TX_TIMEOUT / TX_FAILED); a message in flight, queued-but-unsent, never sent, or already ACKED is rejected. If the failed entry has not yet been dequeued (a caller checking outcomes in the same loop pass the failure was marked), it is rearmed in place with its retry counter reset -- a plain re-enqueue in that window would be rejected as a duplicate. MSG_RACE_START keeps its front-of-queue priority on resend.

This amends the retry policy's "callers that want to retry after a timeout must re-enqueue the message explicitly": explicit retry is now expressed with `txResend()`, so retry POLICY can live outside the transport -- a policy layer says "send it again" without knowing how the bytes were built.

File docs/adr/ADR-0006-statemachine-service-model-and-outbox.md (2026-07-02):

# ADR-0006: State machine declare-intent interface and shared Outbox

**Status:** Accepted (the Outbox portion is a design decision whose
implementation is still pending; the state machine portion is as-built)
**Date:** 2026-07-01

## Context

Coordinated state transitions between the two controllers were correct only
by procedural compliance. Every state handler on both controllers copied the
same three-step ritual -- consume the received state edge, guard, drive the
self-transition -- plus manual hygiene on the `entry`/`exit` one-shot flags
(set by the machine, cleared by hand in every handler). Five handlers per
controller meant ten copies of the ritual.

Two incidents showed the cost of that model:

- A P0-class bug where a handler bypassed the edge-consumption path and fed
  the level-triggered `rx.State` value straight into the follower-transition
  mechanics. The previous heat's stale IDLE re-fired mid-heat and aborted a
  race in progress.
- During the migration itself, deleting the "boilerplate" manual flag clears
  exposed that they were load-bearing: an unconsumed `exit` flag from one
  transition leaked into the next state's handler, which would have disarmed
  the finish-line sensors the moment RACING began.

Separately, each controller carries its own message-outcome bookkeeping
(`PendingTx`): queue-at-event, poll-per-loop, and per-message failure policy
(abort the heat vs. tolerate) hidden inside `checkOutcomes()`. The abort
criteria of ADR-0004 exist only as scattered if-statements.

## Decision

### Declare-intent state machine interface

`stateMachine` (shared by both controllers) exposes exactly four operations
to handlers, plus the abort path:

- `request(raceState next)` -- records intent to transition. Idempotent;
  illegal transitions are ignored (same legality table as before).
- `service(bool holdRx = false)` -- one call per handler pass. In order:
  scrubs any stale `exit` flag, consumes a freshly received state edge
  (follower path), drives a pending request through the send/ACK/commit
  protocol (initiator path). `holdRx` DEFERS the received edge -- never
  discards it -- so the message applies on the first unheld pass.
- `takeEntry()` / `takeExit()` -- return-and-clear accessors, true exactly
  once per transition. Entry persists until the new state's handler consumes
  it; exit is observable only in the pass its transition commits, so
  `takeExit()` must be called after `service()` in the same pass.
- `forceIdle()` -- the abort path, unchanged (see ADR-0004). Aborts are
  deliberately not normal transitions and do not go through `request()`.

The transition mechanics (`selfTransition`, `serviceRx`, `rxTransition`) are
private. The interlock that was previously enforced by every call site doing
three steps in the right order now lives inside the machine, where a call
site cannot get it wrong. The Start Controller's mode machine (`modeSelect`)
mirrors the same shape.

**Rejected: coupling the state machine to the message queue.** The RACING
data-integrity hold ("do not follow COMPLETE while heat messages are still
in flight") could have been automatic if the machine queried the pending
tracker itself. Passing the hold as an argument
(`stm.service(pending.anyPending())`) was chosen instead: the state machine
stays free of messaging dependencies, and the one deliberate hold in the
system is visible in the one handler that needs it.

### Shared Outbox with per-controller policy tables

(Design accepted; implementation pending. Until it lands, the per-controller
`PendingTx` structs described in ADR-0003's consumer pattern remain.)

The two `PendingTx` implementations converge into one engine in
`firmware/lib/shared/`: `track(id)` at the event, `checkOutcomes()` per
loop. Per-message failure policy moves out of code and into a
per-controller policy table (abort-heat vs. tolerate vs. retry-once),
making ADR-0004's abort criteria executable data -- the policy table is the
single place those rows live in code.

**Verdict reporting:** `checkOutcomes()` returns a verdict (e.g. "a fatal
message failed") and the main loop acts on it (calls `forceIdle()`, sends
the error). Rejected alternative: the engine acting on the state machine
directly -- messaging must not own race state.

**`txResend(id)`:** an explicit re-send primitive amends ADR-0003's retry
policy, replacing the re-enqueue idiom for callers that retry after a
terminal status (today only the winner message re-send).

## Consequences

- Any new state handler MUST use the `takeEntry()` / `request()` /
  `service()` / `takeExit()` shape. Direct writes to `target`/`entry`/`exit`
  and per-step transition control are not public API; future architecture
  reviews should not re-suggest exposing them.
- Call-order contract: `takeEntry()` at the top of the handler; `service()`
  once per pass; `takeExit()` after `service()` in the same pass.
- The full coordinated-transition protocol is desktop-testable through the
  public interface against the real serial engine (commit-on-ACK, timeout
  revert, illegal-request rejection, follower commit, holds, stale-edge and
  stale-exit regressions). The interface is the test surface.
- Handlers cannot exercise transition mechanics in isolation anymore; tests
  that need the old surface must drive the machine through `request()` /
  `service()` and the mock wire instead.
- The RACE_TEST self-test's low-level wire ping (raw `txRaceState` /
  `txStatusOf`) is intentionally outside this interface -- it is a test of
  the wire itself, not a state transition.

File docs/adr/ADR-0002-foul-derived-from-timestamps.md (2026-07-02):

# ADR-0002: Foul status is derived from timestamps, not stored as a flag

**Status:** Accepted  
**Date:** 2026-05-21

## Context

During a heat, a foul occurs when a driver triggers their gate before the GO signal fires. The
start controller must track both whether a foul happened and how early the driver jumped (the
reaction time magnitude).

The original design stored this as a separate boolean (`leftFoul`, `rightFoul`) in `raceResultsData`,
set atomically alongside the gate-drop timestamp in `handleEarlyStarts()`. The invariant -- "if
`leftFoul` is true, then `leftStartUs < raceStartUs`" -- was enforced only by calling three
functions in the right order across two states (COUNTDOWN and RACING). Any drift between the
stored flag and the actual timestamp relationship would silently corrupt reaction time calculations.

## Decision

Foul status is derived from the timestamp relationship, not stored. `raceTimingData.isFoul(lane)`
computes from the two timestamps at call time:

- `laneStartUs[lane] == 0`: not triggered -- return false  
- `raceStartUs == 0`: GO has not fired yet, but lane was triggered -- always a foul  
- otherwise: `(int32_t)(laneStartUs[lane] - raceStartUs) < 0` -- triggered before GO

`reactionTimeUs(lane)` subtracts in the correct direction based on `isFoul()`. Both are methods
on `raceTimingData`, which owns all three timestamps. `raceResultsData` and `calcReactionTimes()`
are eliminated.

## Consequences
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

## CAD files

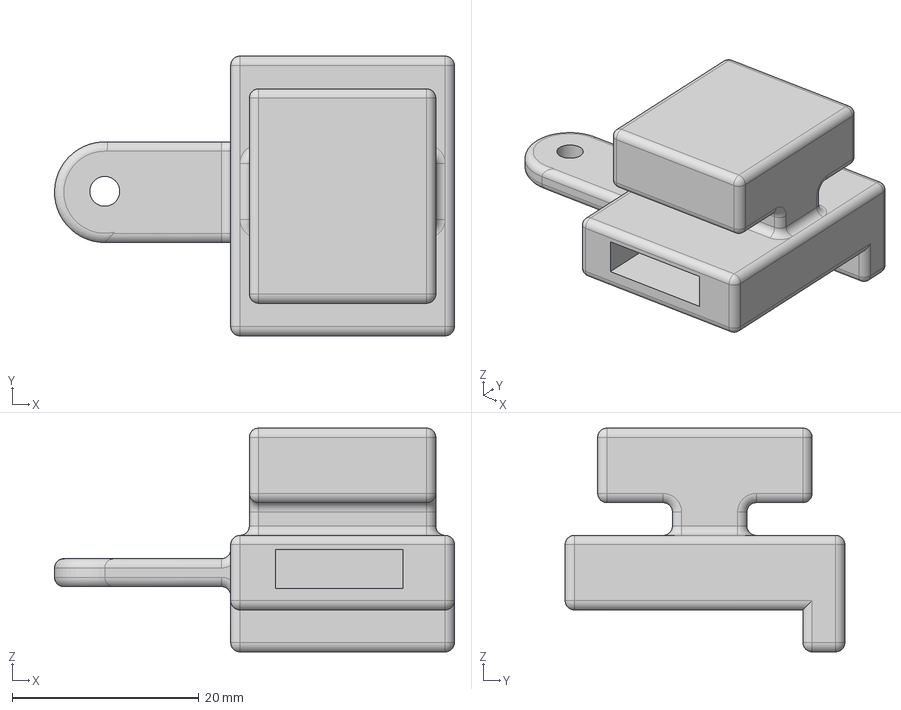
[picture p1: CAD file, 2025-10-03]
hardware/armMagnetHolder/Solenoid_Magnet_Holder.step
42.9 x 30.0 x 24.0 mm

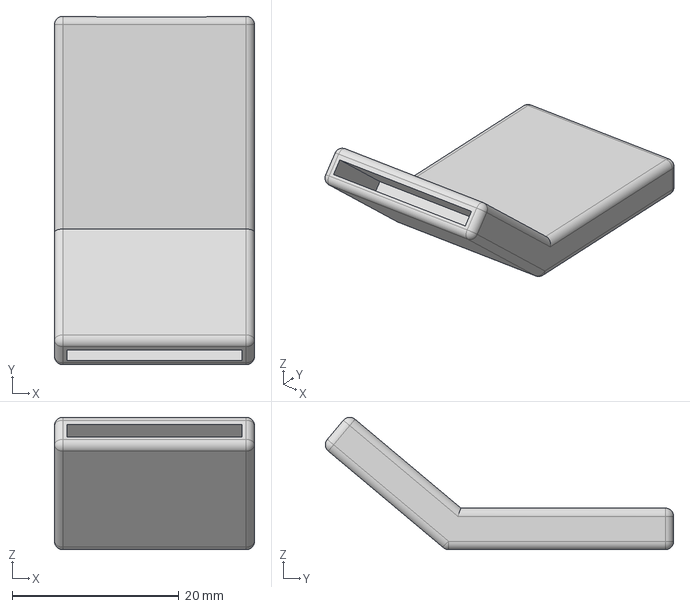
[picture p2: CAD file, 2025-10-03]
hardware/armMagnetHolder/Arm_Magnet_Holder.step
24.0 x 41.8 x 15.9 mm

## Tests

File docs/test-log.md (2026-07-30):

# Test Run Log

Every verification run belongs here: hardware-free (L2 native unit tests) and bench runs alike. Bench procedures live in [bench-test-protocol.md](bench-test-protocol.md).

| Date | Scope | Command | Result | Notes |
|---|---|---|---|---|
| 2026-07-30 | L2 native - 11 suites, plus both targets at `--warnings all` | `pio test -e native` | 111/111 PASSED | Zero-warning compile gate cleared. The Start Controller's `Outbox` declaration omitted the two mask members, drawing two `-Wmissing-field-initializers` warnings; behavior was already correct (omitted aggregate members are value-initialized, and the object is `static`), so the fix states the intent rather than changing it - `pendingMask` / `retriedMask` are now written as explicit zeros at all three declaration sites (both controllers and `test_outbox`), and the usage example in `outbox.h` was updated to match so the header stops prescribing the form that warns. Default member initializers would have been the tidier fix and were rejected on evidence: the AVR core is pinned at `-std=gnu++11`, where an aggregate may not carry them, and the toolchain rejects the resulting brace init outright. Verified: SC 2 warnings -> 0, FC 0 -> 0, both exit 0. SC flash and RAM byte-identical (8830 B / 612 B, measured against a pre-change build of the same source); FC byte-identical (91120 B / 44936 B). |
| 2026-07-25 | L2 native - 11 suites | `pio test -e native` | 111/111 PASSED | P1-9 (countdown recovery) plus the operator-button click policy. Two local escapes added to SC COUNTDOWN, both via `forceIdle()` rather than `request()` because the unrecovered case is a stalled tree WITH a dead link, and `request()` waits on an ACK: (1) a stall watchdog living in `CountDownCtx` (`arm(now)` / `stalled(now)`, 5000 ms - the longest legal countdown is 1500 ms, and 5 s is half the FC's timeout so the SC aborts first and the FC follows), (2) a Mode click. Policy change: Start and Mode now act on the RELEASE edge via a shared `ClickDetector` in buttons.h, replacing three different behaviors across five call sites; lane triggers still act on the press for reaction-timing precision. Fixes a live bug - holding Mode to abort STAGING landed in IDLE, whose entry fabricated `modeReleased = true`, so the same press also advanced the race mode; the Start button had the identical chain out of COMPLETE. Click results are deliberately not latched, so an unread click cannot surface in a later state. New `test_buttons` suite (5 tests, no Arduino dependency); `test_countdown` 5 -> 10 with the stall cases. Both targets compile; SC flash +80 B, RAM +7 B (two detectors, two per-pass flags, fault flag, `startedAt`, less the two deleted release flags); FC untouched. |
| 2026-07-24 | L2 native - 10 suites | `pio test -e native` | 101/101 PASSED | AD-12 (architecture deepening, closes the AD program): `SerialRxState` regrouped by field lifecycle - LEVEL-TRIGGERED, EDGE FLAG, CONSUMER-CLEARED, HEAT-CLEARED, DIAGNOSTIC - with a per-field contract naming who sets it, who clears it, and whether it is safe to read as an event. Every field's set/clear sites were traced through `rxSerial()` and both controllers before classification. `clearHeatEvents()` now states that it owns the HEAT-CLEARED group and only backstops the CONSUMER-CLEARED group. Comment-and-layout only: no renames, no logic, nothing serialized. Corrected one stale comment (`WinnerReceived` claimed "cleared at race start"; it is cleared at IDLE entry). Rider: firmware source converted to plain ASCII per file conventions - 27 characters (arrows, em/en dashes, multiplication sign) across 10 files; the earlier ASCII pass had covered tracked docs only. Both targets compile; SC flash and RAM byte-identical; FC flash byte-identical, RAM +8 B (alignment padding from placing the two int32_t reaction times with their lifecycle group rather than at the end of the struct). |
| 2026-07-03 | L2 native - 10 suites | `pio test -e native` | 101/101 PASSED | AD-3 (architecture deepening, closes the clock-injection trio): blink animation (lights.cpp) and gate return pulse (gates.cpp) got the AD-2 treatment - `updateBlink(now)` / `updateGates(now)` are the real impls, with zero-arg inline wrappers in the headers so the existing call sites are untouched. New `test_ticks` suite (7 tests, includes both .cpp): blink shows pattern1 at start, holds until rate then toggles, runs count*2 half-cycles then applies finalPattern and reports done, count==0 goes straight to final, cancelBlink stops it; gate return not ready until returnWaitMs (500 ms) elapses, dropGate idempotent and per-lane. Mock gained shiftOut (records last pattern) + MSBFIRST. Rider: P2-8 closed - buttons.cpp (poll interval, analog threshold) and lights.cpp (default blink rate) magic numbers are now named constexpr. Both firmware targets compile; SC flash -26 B (the constexpr conversion; behavior unchanged - analogRead range makes the int comparison identical). |
| 2026-07-03 | L2 native - 9 suites | `pio test -e native` | 94/94 PASSED | AD-2 (architecture deepening): christmas-tree countdown made testable via clock injection. `CountDownCtx` moved from startController.cpp into startController.h (next to raceTimingData); `tick()` gained a `now` parameter instead of reading `millis()` internally, so the caller passes `millis()` and tests pass a scripted clock. New `test_countdown` suite (5 tests, header-only - no .cpp/mock-serial): full STAGED->Y3->Y2->Y1->GO at 500 ms in GATEDROP/REACTION, PRO skip-to-Y1 at 400 ms, delay boundary (>=), timer re-anchoring, changed() on transition vs hold, CD_IDLE/CD_GO stable. Both firmware targets compile; SC flash byte-identical (pure restructure). |
| 2026-07-03 | L2 native - 8 suites | `pio test -e native` | 89/89 PASSED | AD-1 (architecture deepening): FC sensor capture logic extracted into one lane-indexed `onBeamBreak(lane, nowUs)`; the two ISRs are now one-line adapters passing `micros()`. Internal per-lane state (`finishTime[2]`, `latched[2]`) replaces the duplicated left/right scalars; public interface and `leftFinished`/`rightFinished` externs unchanged. New `test_sensors` suite (8 tests, real sensors.cpp): not-armed ignore, inside-min-time filter + exact-boundary, valid latch of time & flag, latch-once, lane independence, disarm clears, re-arm resets. Covers the LOGIC half of P1-14 (bench still verifies edge polarity / thresholds). Both firmware targets compile; FC flash byte-identical (pure restructure). |
| 2026-07-03 | L2 native - 7 suites | `pio test -e native` | 81/81 PASSED | AD-7 (architecture deepening, closes the outbox chain): FC adopts the shared Outbox - `PendingTx` struct + `winnerAttempts` counter deleted; one-row policy table MSG_WINNER = RETRY_ONCE. This is the fix for the latent winner-retry no-op found in AD-4: the old re-send landed in the duplicate-rejection window every time and never reached the wire; the engine's RETRY_ONCE uses `txResend()` (rearm-in-place), whose wire-level resend is already pinned by `test_retry_once_resends_identical_bytes`. `winnerMask` now local to handleComplete (engine resends from the captured payload). Main loop acts on verdicts for symmetry with the SC (no FATAL FC entries today). Both firmware targets compile (FC flash grows: engine + txResend linked; SC unchanged). |
| 2026-07-03 | L2 native - 7 suites | `pio test -e native` | 81/81 PASSED | AD-6 (architecture deepening, outbox chain): SC adopts the shared Outbox - hand-written `PendingTx` struct deleted; policy table declares RACE_START/FOUL as FATAL (abort codes per ADR-0004), reaction times / display advance as TOLERATED; `queueHeatMsg()` keeps payload construction SC-owned; main loop acts on the verdict visibly (txError + forceIdle). RACING hold now reads `outbox.anyPending()`. No test changes - regression run confirming zero drift. Both firmware targets compile (SC flash grows: engine + txResend now linked; FC unchanged). |
| 2026-07-02 | L2 native - 7 suites | `pio test -e native` | 81/81 PASSED | AD-5 (architecture deepening, outbox chain): new shared Outbox engine (`firmware/lib/shared/outbox.h`) - per-controller policy table (FATAL/TOLERATED/RETRY_ONCE) turns message outcomes into verdicts; engine reports, main loop acts (ADR-0006). New `test_outbox` suite (9 tests, real serialComm.cpp): ACK clears, FATAL abort verdict with entry code, TOLERATED silent clear, RETRY_ONCE identical-bytes resend / give-up / ACK-of-resend, anyPending, untracked ignored, per-heat retry budget reset. Engine not yet wired into controllers - zero production impact. Both firmware targets compile. |
| 2026-07-02 | L2 native - 6 suites | `pio test -e native` | 72/72 PASSED | AD-4 (architecture deepening, outbox chain): `txResend(id)` added to serialComm - re-send from the tracker's captured payload after TX_TIMEOUT/TX_FAILED. `test_serialcomm` 16 -> 21: identical-bytes resend, same-pass-as-timeout rearm (the window where a plain re-enqueue is silently rejected as a duplicate - the FC's current winner retry hits exactly this), in-flight/never-sent rejection, resend-then-ACK. Both firmware targets compile. |
| 2026-07-02 | L2 native - 6 suites | `pio test -e native` | 67/67 PASSED | AD-11 (architecture deepening, closes the state-machine chain): old transition surface (`selfTransition`/`serviceRx`/`rxTransition`) made private in `stateMachine` and `modeSelect`; the old-vs-new equivalence test retired with it (68 -> 67; its purpose - proving migration parity - is complete). ADR-0006 records the declare-intent interface and Outbox direction. Both firmware targets compile; SC flash byte-identical. |
| 2026-07-02 | L2 native - 6 suites | `pio test -e native` | 68/68 PASSED | AD-10 (architecture deepening): FC handlers migrated to the declare-intent interface; RACING/COMPLETE keep their no-edge-consumption behavior via `service(true)`. Found and closed a latent flag hazard: an unconsumed exit flag from one transition could leak into the next state's `takeExit()` (would have disarmed sensors at RACING entry) - `service()` now scrubs stale exit at the top of each pass, pinned by new test `test_stale_exit_not_inherited_by_next_state`. Both firmware targets compile. |
| 2026-07-01 | L2 native - 6 suites | `pio test -e native` | 67/67 PASSED | AD-9 (architecture deepening): SC handlers migrated to the declare-intent interface (`request`/`service`/`takeEntry`); `modeSelect` gained the same shape. No test changes - regression run confirming zero behavioral drift. Both firmware targets compile; SC flash byte-identical. |
| 2026-07-01 | L2 native - 6 suites | `pio test -e native` | 67/67 PASSED | AD-8 (architecture deepening): `test_state_machine` extended 12 -> 20 tests. Now compiles the real `serialComm.cpp` (same pattern as `test_serialcomm`) so the coordinated-transition protocol runs end-to-end: request/service commit-on-ACK, timeout revert, illegal-request rejection, follower commit, holdRx deferral, stale-`rx.State` P0 regression, forceIdle flags, and an old-vs-new interface equivalence check. Both firmware targets compile clean. |
| 2026-06-12 | L2 native -- 6 suites | `pio test -e native` | 59/59 PASSED | Code-review session. New suites: `test_serialcomm` (16 tests -- real `serialComm.cpp` compiled against the scriptable mock in `firmware/test/shared/Arduino.h`: RX parsing, validation, stale-partial flush, TX retry/timeout/priority/dedup) and `test_display` (7 tests -- digit extraction, rounding, clamp). Expanded: `test_compute` (10 -- new pure TimingInputs interface, clamp + missing-reaction cases), `test_timing` (9 -- N4 zero-raceStart guard, micros() wrap). Both firmware targets also compile clean with `--warnings all`. |
| 2026-05-26 | L2 native -- 4 suites | `pio test -e native` | 30/30 PASSED | Fixed 1 bad test (`test_foul_bits_no_bleed_into_winner` -> `test_foul_left_and_right_no_overlap`): foul/winner masks are separate payloads, not same byte. MinGW required; add `C:\ProgramData\mingw64\mingw64\bin` to PATH first. |

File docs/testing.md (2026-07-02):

# Test Suite Overview

> Reference map for the layered test strategy. The test sources and build
> configs are authoritative for what actually runs; this document tells you
> which layer to use when.

## Philosophy

DerbyTimer uses a layered test strategy: offline tests (L1-L2) catch logic errors without any hardware; integration tests (L3) validate the serial protocol between real Nanos; built-in firmware tests (L4-L5) run on the deployed hardware itself. Hardware bring-up tests live separately under `hardware/` and are used once when assembling a new PCB.

Run the cheapest layer first. Only escalate to hardware when the layer below passes.

---

## Test Layers at a Glance

| Layer | What it tests | Where to find it | How to run |
|---|---|---|---|
| L1 -- Static Analysis | Compiler warnings, undefined behavior, type mismatches | Build flags (`--warnings all`) + cppcheck extension | Compile either controller in VS Code (`Ctrl+Shift+B`) |
| L2 -- Desktop Unit Tests | Pure C++ logic (bitmasks, timing math, state machine transitions) | `firmware/test/native/` | `pio test -e native` |
| L3a -- Serial Protocol Tests | Full UART message exchange between two Nanos | `firmware/fwTest/` | Upload sketches to two Nanos; see `derbySerialTester_Documentation.md` |
| L3b -- UART Monitor | Protocol inspection and scripted injection from a laptop | `firmware/tools/uart_monitor.py` | `python firmware/tools/uart_monitor.py <COMx>` |
| L4 -- RACE_TEST Self-Test | All peripherals on both controllers (lights, gates, sensors, display, comms) | Built into firmware | Hold MODE button at power-up; read results from lights/display |
| L5 -- Debug Serial Mode | State transitions, TX/RX events, sensor fires logged over serial | `firmware/lib/shared/debug.h` | Compile with `-DDERBY_DEBUG`; open serial monitor at 115200 |
| Hardware Tests | Board-level peripheral bring-up after PCB assembly | `hardware/hwTest/` | Upload standalone `.ino` sketch; follow `.md` checklist |

---

## L2 Desktop Unit Tests -- Details

**Location:** `firmware/test/native/`

| Suite | What it covers |
|---|---|
| `test_bitmasks/` | Bitfield encoding/decoding for foul, winner, and mode flags |
| `test_compute/` | Car time calculation (reaction subtraction, foul addition, clamping, winner/DNF logic) |
| `test_display/` | Display digit extraction: us-to-ms rounding, 99.998 clamp, 88.888 sentinel |
| `test_serialcomm/` | The real protocol engine (`serialComm.cpp`): RX parsing per message, payload validation, stale-partial flush, TX ACK/retry/timeout/priority/dedup |
| `test_state_machine/` | Allowed-transition table enforcement for all state pairs |
| `test_timing/` | Overflow-safe microsecond elapsed-time arithmetic, foul/reaction edge cases |

**Mocks:** `firmware/test/shared/Arduino.h` is a scriptable mock of the Arduino API: feedable serial RX buffer, captured TX buffer, and controllable `millis()`/`micros()`. It is deliberately named `Arduino.h` so that production sources' `#include <Arduino.h>` resolves to it in the native build -- this is how `test_serialcomm` compiles the real `serialComm.cpp` instead of a copy. It cannot collide with real builds: only the `[env:native]` include path (`-I firmware/test/shared`) sees it; arduino-cli, PlatformIO embedded builds, and the Arduino IDE never look inside `firmware/test/`. (`arduino_mock.h` is a compatibility shim that includes it.)

**To run (pick one):**

1. **VS Code (easiest):** `Terminal > Run Task... > Run L2 Native Tests`
   (defined in `.vscode/tasks.json`).
2. **PlatformIO terminal:** Command Palette (`Ctrl+Shift+P`) >
   `PlatformIO: New Terminal`, then `pio test -e native`. This terminal has
   `pio` on its PATH; a plain PowerShell/CMD terminal does NOT.
3. **Any terminal, full path:**

```sh
& "$env:USERPROFILE\.platformio\penv\Scripts\pio.exe" test -e native   # PowerShell
```

Note: typing `pio test -e native` into the Command Palette itself does
nothing -- the palette runs editor commands, not shell commands. Use one of
the three routes above. Expected result: every test case succeeds; the
current case count and run history live in [test-log.md](test-log.md).

Requires MinGW GCC on Windows: `choco install mingw` (Chocolatey sets the PATH permanently; open a new terminal after installing). PlatformIO VS Code extension also required (it installs `pio.exe` under `%USERPROFILE%\.platformio\penv\`).

---

## L3a Serial Protocol Tests -- Details

**Location:** `firmware/fwTest/`

Two sketches run on two separate Arduino Nanos wired cross-connected (D5/D6 SoftwareSerial):

- `derbySerialTester.ino` -- interactive test driver; sends messages and checks ACK/NACK/retry behavior
- `derbySerialResponder.ino` -- simulates the peer controller; responds to messages

Full wiring diagram, command reference, and test protocol: `firmware/fwTest/derbySerialTester_Documentation.md`

---

## See Also

- **Two-board integration bench protocol: [docs/bench-test-protocol.md](bench-test-protocol.md)** -- staged bring-up checklist, FTDI tap/simulator wiring, symptom table
- Race self-test result codes: [docs/race-test-codes.md](race-test-codes.md)
- Hardware test procedures: [hardware/hwTest/](../hardware/hwTest/)
- Wire protocol byte-level reference: [docs/protocol.md](protocol.md)

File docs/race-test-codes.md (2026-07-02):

# RACE_TEST Failure Code Reference

Print this sheet and store it with the timer hardware. The codes are defined
by the RACE_TEST implementation in the firmware -- reprint this sheet if they
change.

## Entry

**Start Controller:** Hold the MODE button during power-up.
**Finish Controller:** Enters RACE_TEST automatically when SC triggers it.

Both controllers can also be triggered by sending `MSG_RACE_STATE(RACE_TEST)` over UART.

## Failure Codes

| Code | Controller | Phase | Meaning |
| ---- | --- | ----- | --- |
| **101** | SC | Phase 2 - Gates | Left gate did not reach ready state within 600 ms |
| **102** | SC | Phase 2 - Gates | Right gate did not reach ready state within 600 ms |
| **103** | SC | Phase 3 - Buttons | Start button not detected within 5 seconds |
| **104** | SC | Phase 3 - Buttons | Mode button not detected within 5 seconds |
| **105** | SC | Phase 3 - Buttons | Left lane button not detected within 5 seconds |
| **106** | SC | Phase 3 - Buttons | Right lane button not detected within 5 seconds |
| **107** | SC | Phase 0 - FC Comm | FC did not respond to communication ping (non-fatal; test continues) |
| **201** | FC | Phase 2 - Sensors | Left sensor: no beam-break detected within 8 seconds |
| **202** | FC | Phase 2 - Sensors | Right sensor: no beam-break detected within 8 seconds |
| **203** | FC | Phase 3 - SC Comm | SC communication ping not received within 3 seconds |

## SC Result Indicators (lights)

| Result | Pattern |
| --- | --- |
| All pass | GO (green) blinks 5x then stays on |
| Any failure | FL + FR (red) blinks N times where N = number of failed codes, pauses 1s, repeats |

## FC Result Indicators (displays)

| Result | Display |
| --- | --- |
| All pass | Both lanes show `00.000` |
| Any failure | Both lanes cycle: code (2s), blank (1s), next code (2s), ..., `88.888` end marker (1s), repeat |

Failure codes display as `00.XXX` where XXX is the 3-digit code.
Example: code 107 displays as `00.107`.

## SC Test Sequence

| Phase | What Happens | Observable |
| ----- | --- | --- |
| 0 | Pings FC over UART, waits 2s for ACK | Blue lights blink 3x (pass) or red blink 1x (code 107) |
| 1 | Chases all 8 lights L-to-R then R-to-L (150ms each); 3x all-on/all-off (500ms each) | Watch for dead LEDs |
| 2 | Returns both gates (hold 600ms), drops left (300ms), drops right (300ms) | Watch gates physically |
| 3 | Prompts each button: START, MODE, LEFT lane, RIGHT lane (5s each) | GO blinks = press a button; brief confirm blink = button detected |
| Result | GO stays green (all pass) or red blinks repeat (failures) | -- |

## FC Test Sequence

| Phase | What Happens | Observable |
| ----- | --- | --- |
| 1 | Shows `88.888` on both lanes (1s), then counts down `05.000` to `01.000` (500ms each) | Watch for dead display segments |
| 2 | Arms sensors; both lanes count up live | Wave hand in front of each sensor; display freezes at captured time |
| 3 | Waits 3s for SC communication confirmation | Internal only |
| Result | `00.000` (all pass) or failure code cycle | -- |

## Notes

- Light test (SC Phase 1) and display test (FC Phase 1) are visual-only. No failure code is generated -- observe directly.
- Gate test is physical -- watch for gates to rise and drop.
- Button test is interactive -- press each button when the GO light is blinking.
- Sensor test is interactive -- wave your hand in front of each sensor beam after the countdown ends.
- Code 107 is non-fatal: SC continues all remaining test phases even if FC is not responding.
- Sensor minimum trigger time is 500ms after arm; wave your hand after the display starts counting.

## Exiting RACE_TEST

Power-cycle both controllers to exit. Future: remote `MSG_RACE_STATE(IDLE)` from Race Manager.

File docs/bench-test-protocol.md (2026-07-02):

# Bench Test Protocol: Two-Board Integration

Standalone procedure for bringing up and verifying the Start Controller (SC)
and Finish Controller (FC) together on the bench. Written to be followed
cold -- no memory of past sessions assumed. Record every run in
`docs/test-log.md`.

Related docs: [testing.md](testing.md) (layer map) | [protocol.md](protocol.md)
(wire format) | [race-test-codes.md](race-test-codes.md) (self-test codes)

---

## 1. The diagnostic toolkit (read first)

**There are no breakpoints in this workflow.** Neither board supports
debugger-based development without extra probe hardware, and pausing one
controller mid-heat makes the other's 50 ms ACK timeouts and 10 s abort
timers fire -- you would be debugging the pause, not the system. Everything
below is observe-while-running.

Your three windows into the system, in order of usefulness:

1. **FC debug stream (primary).** Build the FC with `DERBY_DEBUG` and leave
   its USB plugged into the laptop with a serial monitor open at 115200.
   This is safe during live racing: the wire protocol runs on Serial1
   (D0/D1), debug text goes to USB. You will see every state transition,
   sensor finish, computed time, and winner mask as they happen.
2. **SC lights (secondary).** The SC runs a NORMAL build; its tree lights
   are its telemetry. Blue = staging, yellow sequence = countdown,
   green = GO, red patterns = errors (see race-test-codes.md).
3. **Protocol tap / simulator (when 1+2 are not enough).** The SH-U09C
   USB-TTL adapter (FTDI FT232RL) either watches the wire passively or
   *becomes* one of the controllers. Details in section 3.

**HARD RULE -- SC flashing:** the classic Nano's D0/D1 pins are shared
between the comm link and its onboard USB-serial bridge. **Disconnect the
comm cable from the SC's J5 before flashing or opening a USB serial monitor
on the SC.** Two drivers on the same pins can corrupt the upload and the
protocol. (The FC has no such restriction -- its USB is independent.)

### Build and flash commands

```sh
# FC with debug output (the bench workhorse):
arduino-cli compile --fqbn arduino:mbed_nano:nano33ble --library firmware/lib/shared --build-property "build.extra_flags=-DDERBY_DEBUG" firmware/finishController/finishController.ino
arduino-cli upload  --fqbn arduino:mbed_nano:nano33ble -p <FC-COM-port> firmware/finishController/finishController.ino

# SC normal build (comm cable DISCONNECTED while uploading):
arduino-cli compile --fqbn arduino:avr:nano --library firmware/lib/shared firmware/startController/startController.ino
arduino-cli upload  --fqbn arduino:avr:nano -p <SC-COM-port> firmware/startController/startController.ino
```

VS Code tasks "Compile FC Debug" etc. in `.vscode/tasks.json` are
equivalents. Any serial monitor works for the FC debug stream (VS Code,
Arduino IDE, PuTTY, Docklight) at 115200.

---

## 2. Wiring reference

```
SC (5V TTL)                              FC board
J5 Comm  ----- comm cable (5V TTL) ----- J2 Comm --[level shifter]-- Nano33BLE D0/D1 (3.3V)
```

The cable itself carries **5 V TTL in both directions** -- the FC board's
level shifter sits between J2 and the Nano 33 BLE. Two signal lines:

- **SC-TX line** (SC D1 -> FC): carries SC->FC messages
- **FC-TX line** (FC -> SC D0): carries FC->SC messages

---

## 3. Using the SH-U09C FTDI adapter

Set the **voltage jumper to 5 V** for everything in this document (you only
ever connect at the cable / J5 / J2, which are all on the 5 V side of the
FC's level shifter). 3.3 V would only apply if probing directly at the
Nano 33 BLE's D0/D1 pins -- don't, use the connector side.

Never connect the adapter's VCC pin to the boards; they are self-powered.
GND must always be common.

### 3a. Passive tap (watch the live conversation)

- Adapter **GND** -> system GND
- Adapter **RX** -> the signal line you want to watch
- Adapter TX -> **leave unconnected**

One adapter watches ONE direction at a time. Tap the SC-TX line to see
SC->FC traffic (states, race start, reactions, fouls); tap the FC-TX line
to see FC->SC traffic (ACKs, winner, completion).

**Tool choice:**

- **First: `firmware/tools/uart_monitor.py`** -- it decodes DerbyTimer
  messages by name, which no generic terminal can do.

  ```sh
  pip install pyserial          # once
  python firmware/tools/uart_monitor.py COM5 --log bench-run.txt
  # then choose [1] Passive Monitor
  ```

- **Second: Docklight** (or any raw-hex terminal) -- when you suspect the
  decoder is hiding something: framing corruption, stray bytes, or timing
  gaps. Timestamped raw hex shows the wire exactly as it is. 115200 8N1.

### 3b. Simulator endpoint (laptop BECOMES the missing controller)

This is the most valuable pre-heat test: each real board gets a full
integration test against a scripted partner before the two boards ever meet.

Wiring (adapter replaces the absent board; note the cross-over):

- Adapter **TX** -> device RX line, Adapter **RX** -> device TX line,
  GND common. Against the real SC connect at J5; against the real FC
  connect at J2.

Run `python firmware/tools/uart_monitor.py <COM>` and pick:

- **[3] FC Simulator** against the **real SC**: the laptop ACKs everything
  and sends a winner on keypress. Walk the SC through a full heat with the
  buttons and watch its lights behave.
- **[2] SC Simulator** against the **real FC**: the laptop walks the state
  sequence and sends RACE_START; trigger the finish sensors by hand and
  confirm the FC computes/displays times and sends MSG_WINNER.
- **[4] Protocol Injector** for ad-hoc poking (send any message, observe
  the response; good for testing NACK/bounds-check behavior).

---

## 4. Staged bring-up checklist

Do the stages in order. Do not skip ahead past a failure -- each stage
assumes the previous one passed. Log each stage's result in test-log.md.

### Stage 0 -- Power-only smoke

Power each board (no comm cable). Expect: SC lights off after boot blip;
FC displays blank. No hot components, no magic smoke.

### Stage 1 -- L4 self-test, each board standalone

Hold the SC MODE button at power-up to enter RACE_TEST. Without the comm
cable, SC Phase 0 (FC ping) is EXPECTED to fail with one red blink + code
107 -- that is correct behavior, continue through the light chase, gate
cycle, and button phases. FC: run its functional checks via the hardware
test sketches in `hardware/hwTest/` if not already done at assembly.
Result codes: race-test-codes.md.

### Stage 2 -- Simulator integration, each board alone (section 3b)

- Real SC + laptop FC-sim: full GATEDROP and REACTION sequences from the
  buttons. Pass = SC lights walk the states and win lights fire on the
  simulated winner.
- Real FC + laptop SC-sim: scripted heat with hand-triggered sensors.
  Pass = FC debug stream shows `->RACING`, `left/right finish us=`,
  plausible times on the displays, `winner mask=` sent.

### Stage 3 -- Two-board link check

Comm cable connected, both boards powered, FC USB debug monitor open.
Hold SC MODE at power-up (RACE_TEST). Phase 0 pings the FC over the real
cable:

- **3 blue blinks** = link good both directions. Proceed.
- **1 red blink + code 107** = link dead. Check: TX/RX not crossed
  (SC TX must arrive at FC RX), GND common, cable seated at J5/J2.
  Tap each line per 3a to see which direction is silent.

### Stage 4 -- First GATEDROP heat

1. Both boards idle. FC debug monitor open.
2. SC: Start -> STAGING (blue lights; gates return). Load nothing yet.
3. Start again -> COUNTDOWN -> GO (gates drop).
4. Hand-trigger each finish sensor (block the beam) a second or two apart.
   Remember the 500 ms minimum-race-time filter: triggers in the first
   half second after GO are ignored by design.
5. Expected FC debug lines, in order:
   `[FC] ->STAGING`, `[FC] ->COUNTDOWN`, `[FC] ->RACING`,
   `[FC] left finish us=...`, `[FC] right finish us=...`,
   `[FC] ->COMPLETE`, `[FC] winner mask=...`
6. Expected hardware: FC displays show two plausible times; SC win lights
   blink for the faster lane; Start press advances/clears the displays;
   both boards return to IDLE (SC lights off, FC blank).
7. Repeat 3 heats. Times should be stable and sane.

### Stage 5 -- REACTION heat, foul, and abort recovery

1. SC: MODE button to REACTION (Y2 confirmation blink).
2. Clean heat: hold both lane buttons through GO, release after GO,
   hand-trigger the sensors. Expect reaction times in the FC debug stream
   and on the second display page (Start press advances to it).
3. **Foul heat (verifies the foul-reaction fix):** release ONE lane during
   the countdown (before GO). Expect: red foul light overlay on that side,
   `[FC] rx foul:` and a `react us=` line for the FOULED lane in the debug
   stream, fouled lane's display blank at COMPLETE, other lane wins.
4. **Abort recovery (verifies timeout paths):** start a heat and pull the
   comm cable during COUNTDOWN. Expect: SC's RACE_START times out ->
   SC returns to IDLE (3 red blinks at IDLE entry = sync warning); FC's
   10 s countdown timeout -> `[FC] countdown timeout->forceIdle`, displays
   blank. Reconnect the cable; the next heat must run normally with no
   power cycle.

### Stage 6 -- Record

Append a test-log.md row: date, stages run, pass/fail per stage, measured
oddities (time skew, retry noise in the tap log), firmware commit hash.

---

## 5. Symptom -> likely cause

| Symptom | Likely cause / first check |
| --- | --- |
| SC Phase-0 ping fails (code 107) | TX/RX crossed at J5/J2, missing GND, cable unseated. Tap each line (3a) to find the silent direction. |
| SC GO light goes dark seconds after GO, heat dies | Stale-state regression (serviceRx) -- check FC debug for an unexpected `->IDLE`; tap SC->FC line for a spurious MSG_RACE_STATE. |
| FC never arms / no finish times | MSG_RACE_START not arriving: watch FC debug at GO; tap the SC-TX line for ID 0x05 at GO. |
| Times look uniformly long/short by tens of ms | RACE_START retries delaying t0 -- tap log will show repeated 0x05 sends; check cable integrity. |
| Reaction times missing (car times = race times) | FC debug shows the missing-react warning; tap SC-TX for MSG_LEFT/RIGHT_REACT after GO; in GATEDROP mode this is normal. |
| Fouled lane shows a time instead of blank | Foul flag lost -- FC debug should show `rx foul:` at RACING entry; tap for MSG_FOUL (ID 0x09). |
| Garbage on the displays / NACK storms in the tap log | Wire corruption: shorten the cable, check GND, try a lower baud rate as a diagnostic. |
| SC won't flash / upload errors | Comm cable still connected to J5 -- disconnect it (hard rule, section 1). |
| One direction silent in taps but boards seem half-working | One conductor broken in the cable; ACKs vanish -> every message retries 4x then fails. |

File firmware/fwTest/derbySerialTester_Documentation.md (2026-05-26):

# DerbyTimer Serial Protocol Test Harness

## Overview

Two-Nano test rig that verifies the UART wire protocol in isolation — no PCBs or sensors required.

- **Tester Nano** — runs `derbySerialTester.ino`, sends test messages over SoftwareSerial, reports results via USB serial to PC
- **Responder Nano** — runs `derbySerialResponder.ino`, parses inbound bytes, ACKs (or NACKs/silences per mode)

## Wiring

```text
Tester Nano                    Responder Nano
  D5 (TX) ───────────────────> D0 (RX)
  D6 (RX) <─────────────────── D1 (TX)
  GND ──────────────────────── GND
  USB -> PC (serial monitor)   USB -> PC (for flashing only)
```

## Compile and Flash

Both sketches are self-contained — no `--library` flag needed:

```bash
arduino-cli compile --fqbn arduino:avr:nano firmware/fwTest/derbySerialTester.ino
arduino-cli compile --fqbn arduino:avr:nano firmware/fwTest/derbySerialResponder.ino
```

Flash Tester to Nano A. Flash Responder to Nano B. Cross-wire per diagram above.

## Running Tests

Open serial monitor on the Tester's USB port at 115200 baud.

Press `a` to run all tests, or use individual keys:

| Key | Test |
| --- | ---- |
| `a` | Run ALL tests |
| `1` | MSG_RACE_MODE (all 4 modes) |
| `2` | MSG_RACE_STATE (all 6 states) |
| `3` | MSG_RACE_START (priority message) |
| `4` | MSG_LEFT_REACT + MSG_RIGHT_REACT (4-byte payload, positive/negative/zero/INT32_MAX) |
| `5` | MSG_FOUL (foul_left, foul_right, foul_both) |
| `6` | MSG_WINNER (leftWin, rightWin, tie, noResult) |
| `7` | MSG_DISP_ADVANCE (zero payload) |
| `8` | MSG_ERROR — verify ACK received (P2-15 fix) |
| `9` | NACK retry — Responder NACKs first attempt, ACKs second |
| `t` | Timing stress — 50 MSG_RACE_MODE messages; min/max/avg round-trip |
| `e` | Error handling — NACK retry, max retries (TX_FAILED), timeout |
| `r` | Reset Responder mode to ACK_ALL, send IDLE state |
| `s` | Full race sequence: IDLE->STAGING->COUNTDOWN->RACING->COMPLETE->IDLE + WINNER |
| `p` | Print current stats |
| `h` | Help |

## Responder Mode Control

The Tester configures the Responder by sending byte `0xFD` followed by a mode byte.
The Tester's `setRespMode()` calls this automatically before each relevant test.

| Mode | Behavior |
| ---- | --- |
| `0x00` | ACK all messages (default) |
| `0x01` | NACK next message, then revert to ACK_ALL |
| `0x02` | NACK all messages until explicitly changed |
| `0x03` | No response to next message (silent), then revert to ACK_ALL |

## Test Output Format

```text
[TEST] MSG_RACE_MODE (all 4 modes)
  TX: 0x3 [0]
  RX: 0x1 [3] (842 us)
  PASS: ACK ok
  TX: 0x3 [1]
  RX: 0x1 [3] (810 us)
  PASS: ACK ok

========== TEST SUMMARY ==========
Total: 24  Pass: 24  Fail: 0  Timeout: 0
Round-trip us  min: 803  max: 1201  avg: 921
==================================
```

## Troubleshooting

| Symptom | Likely Cause | Fix |
| --- | --- | --- |
| All tests timeout | TX/RX wires swapped | Swap D5 and D6 on Tester side |
| All tests timeout | Baud mismatch | Verify both boards at 115200 |
| Intermittent timeouts | SoftwareSerial jitter at high baud | See P2-36 for baud rate evaluation |
| NACK instead of ACK | Payload byte count mismatch | Check MsgID enum order in both sketches matches serialComm.h |
| Wrong ACK ID | MSG_ERROR not ACKed | Verify P2-15 fix is in serialComm.cpp |

## Protocol Independence

Both sketches define local copies of the protocol constants (MsgID enum, bitmask values) rather
than including `serialComm.h`. This keeps the harness independent of the production library —
a bug in `serialComm.cpp` does not mask itself in the test output.

If the production protocol changes (new message ID, different payload size), update both
`derbySerialTester.ino` and `derbySerialResponder.ino` to match `serialComm.h`.

## Response Time Guidelines

| Category | Typical | Concerning |
| --- | --- | --- |
| ACK for 1-byte msg | 500-1500 us | > 5 ms |
| ACK for 4-byte msg | 1000-2500 us | > 10 ms |
| Race start to ACK | < 2 ms | > 5 ms |

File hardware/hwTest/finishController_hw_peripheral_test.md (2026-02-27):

# Finish Controller Hardware Peripheral Test

## 1. Objective

The objective of this test is to perform basic checkout of the Finish Controller PCB before software/firmware integration. This test checks all external connectors, all voltage regulators, and sensor input signal conditioning circuits.

---

## 2. Background

The Finish Controller board is part of the derby timer system and is designed to be a custom Arduino shield at the finish end of the race track.  Its major functions are:

- Accept & amplify optical sensor inputs from two independent World Beam QS-18 series optical sensors (Lane 1 and Lane 2)
- Provide time-display output signals that drive two 5-digit 7-segment LED digit displays with multiplexed selection
- Accept and condition +12V external power to +5V, and +3.3V power rails
- Communicate with the Start Controller via logic-level-shifted UART serial communication
- Communicate with the Race Manager controller via BLE interface (future firmware integration)

This peripheral test validates basic board functionality at the component level before microprocessor integration.

---

## 3. Equipment Required

- Digital multimeter with DC voltage measurement capability
- External 12VDC regulated power supply
- Pair of optical sensors (World Beam QS-18 series) for stimulation testing
- Jumper wires (22 AWG) for temporary connections
- Schematic printouts (optional, for reference during testing)

---

## 4. Setup and Configuration

### 4.1 Pre-Test Visual Inspection

1. Confirm PCB is fully mounted in its housing and all solder joints are clean and complete
2. Confirm PCB to enclosure connectors are properly seated and have continuity to enclosure connectors

### 4.2 Power Supply Configuration

1. Set  12V power supply to **12.0V**
2. Enable current limiting feature on supply (if available)
3. Confirm channel output is **OFF** until directed in test procedure

### 4.3 Peripheral Connection

Connect all external peripherals to the Finish Controller board as follows:

1. **Power Supply**: Connect external 12V power supply to connector **J3** (2-pin power input)
   - Pin 1: +12V
   - Pin 2: GND
2. **SENSOR INPUT**: Connect to connector **J1** (3-pin sensor input)
   - Pin 1: +12V reference (internal supply to sensors)
   - Pin 2: Lane 1 digital output (to be stimulated with optical sensor)
   - Pin 3: Lane 2 digital output (to be stimulated with optical sensor)
   - Pin 4: GND reference
3. **DISPLAY POWER**: Connect to connector **J6** (4-pin display power)
   - Pin 1: +12V (for LED display back-light, if present)
   - Pin 2: GND
   - Pin 3: GND (additional ground for display)
   - Pin 4: +5V (for display segment driver logic)

---

## 5. Test Procedure

### 5.1 Power Supply Verification Test

**Objective**: Verify all voltage regulators produce output within specification.
**Test Steps**:

1. **SAFETY CHECKPOINT**: Before applying power, confirm
   - All connectors are properly seated
   - No visible solder bridges or defects
2. Turn **ON** 12V power supply output.  Immediately check and observe for:
   - Unusual noises or smells
   - Evidence of arcing or overheating
   - Discoloration or odor
3. Place multimeter ground probe on J8 Pin 14 (GND reference)
4. Measure voltage on +12V rail:
   - Verify +12V LED indication is illuminated (D17)
   - Place test probe on J8 pin 15
   - Expected reading: **12.0V**, actual: _______ V
5. Measure voltage on +5V rail:
   - Verify +5V LED indication is illuminated (D16)
   - Place test probe on J6 pin 4
   - Expected reading: **5.0V**, actual: _______ V
6. Measure voltage on +3.3V rail:
   - Verify +3.3V LED indication is illuminated (D15)
   - Place test probe on via near C6 pin 1 (3.3V output test point)
   - Expected reading: **3.3V**, actual: _______ V
7. If voltages are outside tolerance, STOP testing and investigate voltage regulator circuits

**Pass Criteria**: All three voltage measurements within specified tolerances

---

### 5.2 Sensor Input Test

**Objective**: Verify sensor input signal conditioning circuits (Schmitt triggers) are functional.

**Test Lane 1 Sensor Input**:

1. Place multimeter ground probe on J8 Pin 14 (GND reference)
2. Place multimeter test probe on **J8 Pin 5** (Lane 1 sensor input signal)
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

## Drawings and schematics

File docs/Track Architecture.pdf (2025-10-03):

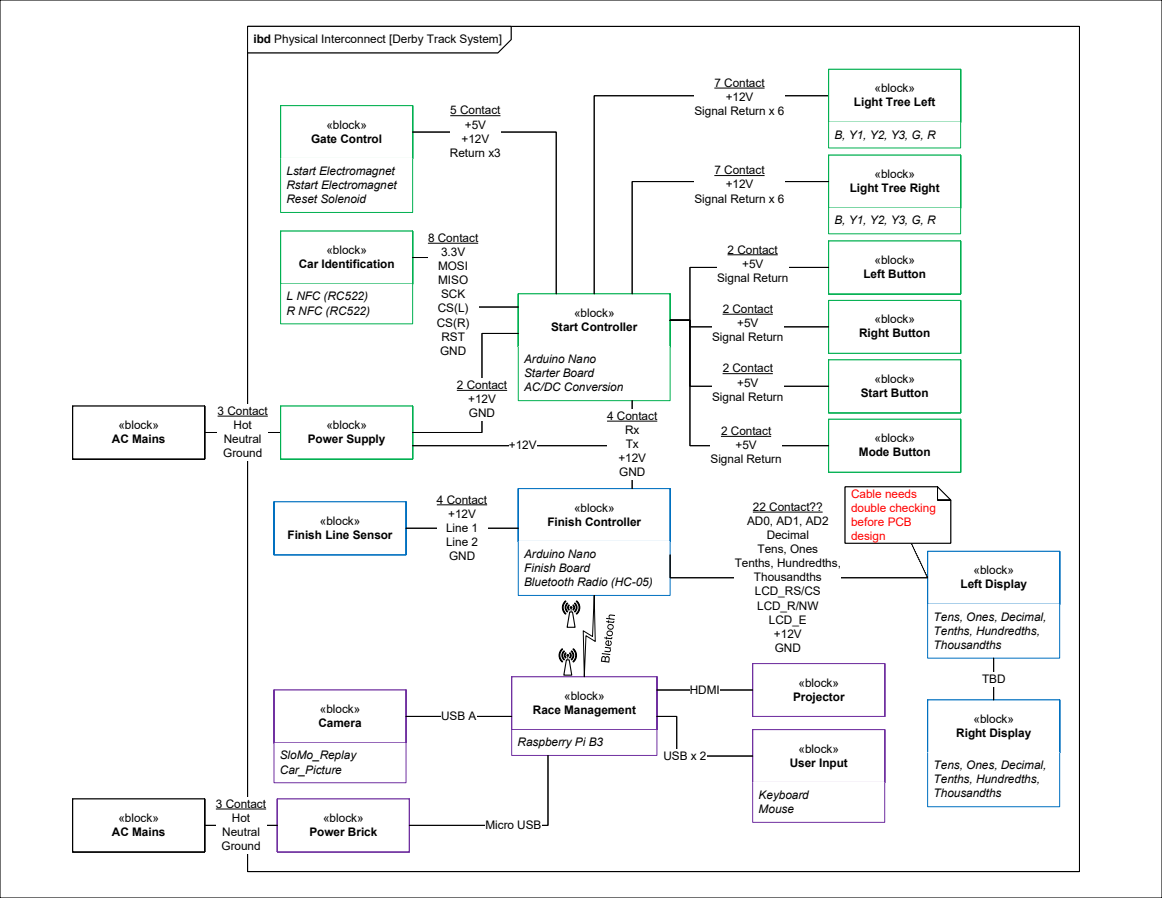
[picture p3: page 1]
«block» Finish Controller; «block» Race Management; Raspberry Pi B3; «block» Gate Control; «block» Left Button; «block»; AC Mains; Mode Button; 4 Contact +12V Line 1 Line 2 GND; «block» Projector; «block» User Input; HDMI; USB x 2; Camera; USB A; Keyboard Mouse; SloMo_Replay Car_Picture; «block» Car Identification; «block» Start Controller; «block» Left Display; Lstart Electromagnet Rstart Electromagnet Reset Solenoid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

ibd Physical Interconnect [Derby Track System]

«block»
Light Tree Left

Light Tree Right

Arduino Nano
Starter Board
AC/DC Conversion

Finish Line Sensor

Finish Board
Bluetooth Radio (HC-05)

Tens, Ones, Decimal,
Tenths, Hundredths,
Thousandths

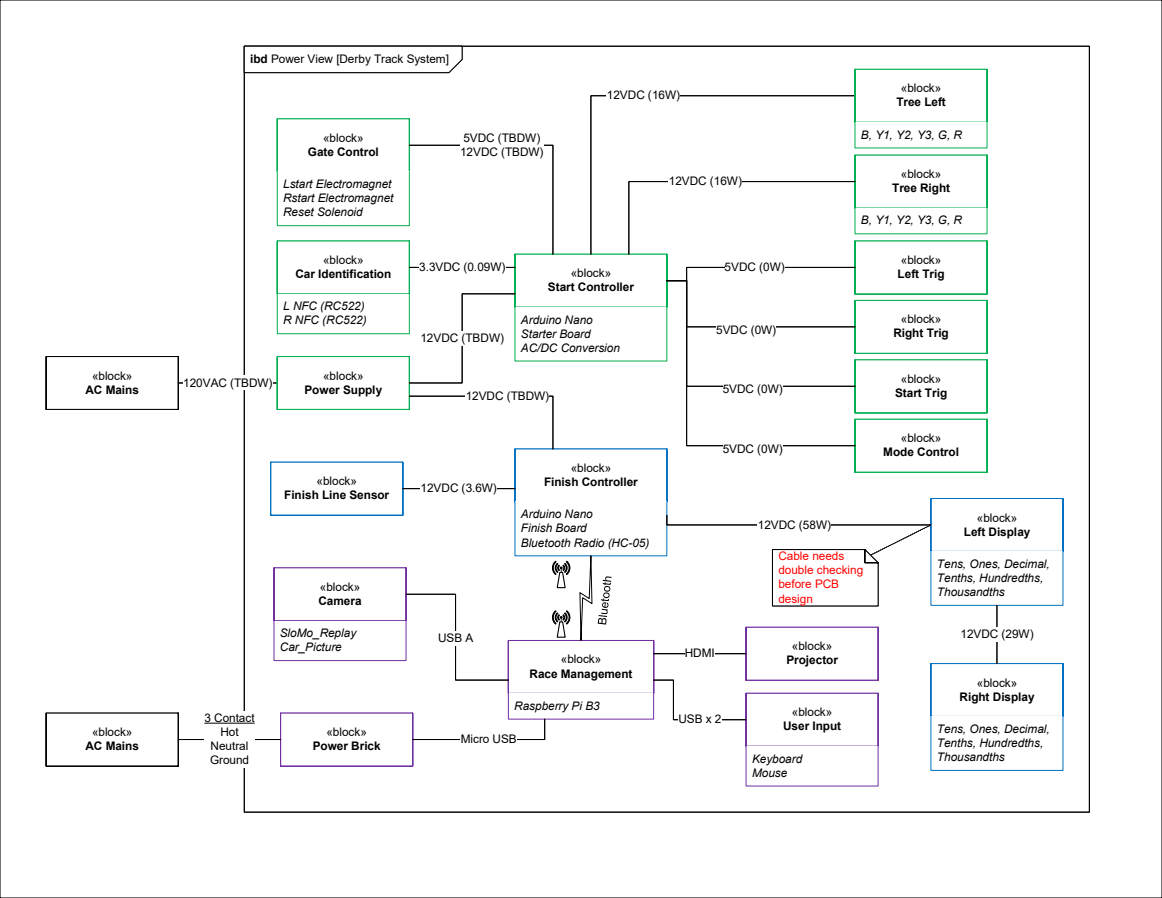
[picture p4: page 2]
«block» Finish Controller; «block» Race Management; Raspberry Pi B3; «block» Gate Control; «block» Left Trig; «block» AC Mains; «block» Mode Control; 12VDC (3.6W); «block» Projector; «block» User Input; HDMI; USB x 2; «block» Camera; USB A; Keyboard Mouse; SloMo_Replay Car_Picture; «block»; Car Identification; Start Controller; «block» Left Display; Lstart Electromagnet Rstart Electromagnet Reset Solenoid; 12VDC (58W); 5VDC (TBDW) 12VDC (TBDW); 5VDC (0W); 12VDC (16W); Tree Left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

ibd Power View [Derby Track System]

Arduino Nano
Starter Board
AC/DC Conversion

«block»
Finish Line Sensor

Finish Board
Bluetooth Radio (HC-05)

Tens, Ones, Decimal,
Tenths, Hundredths,
Thousandths

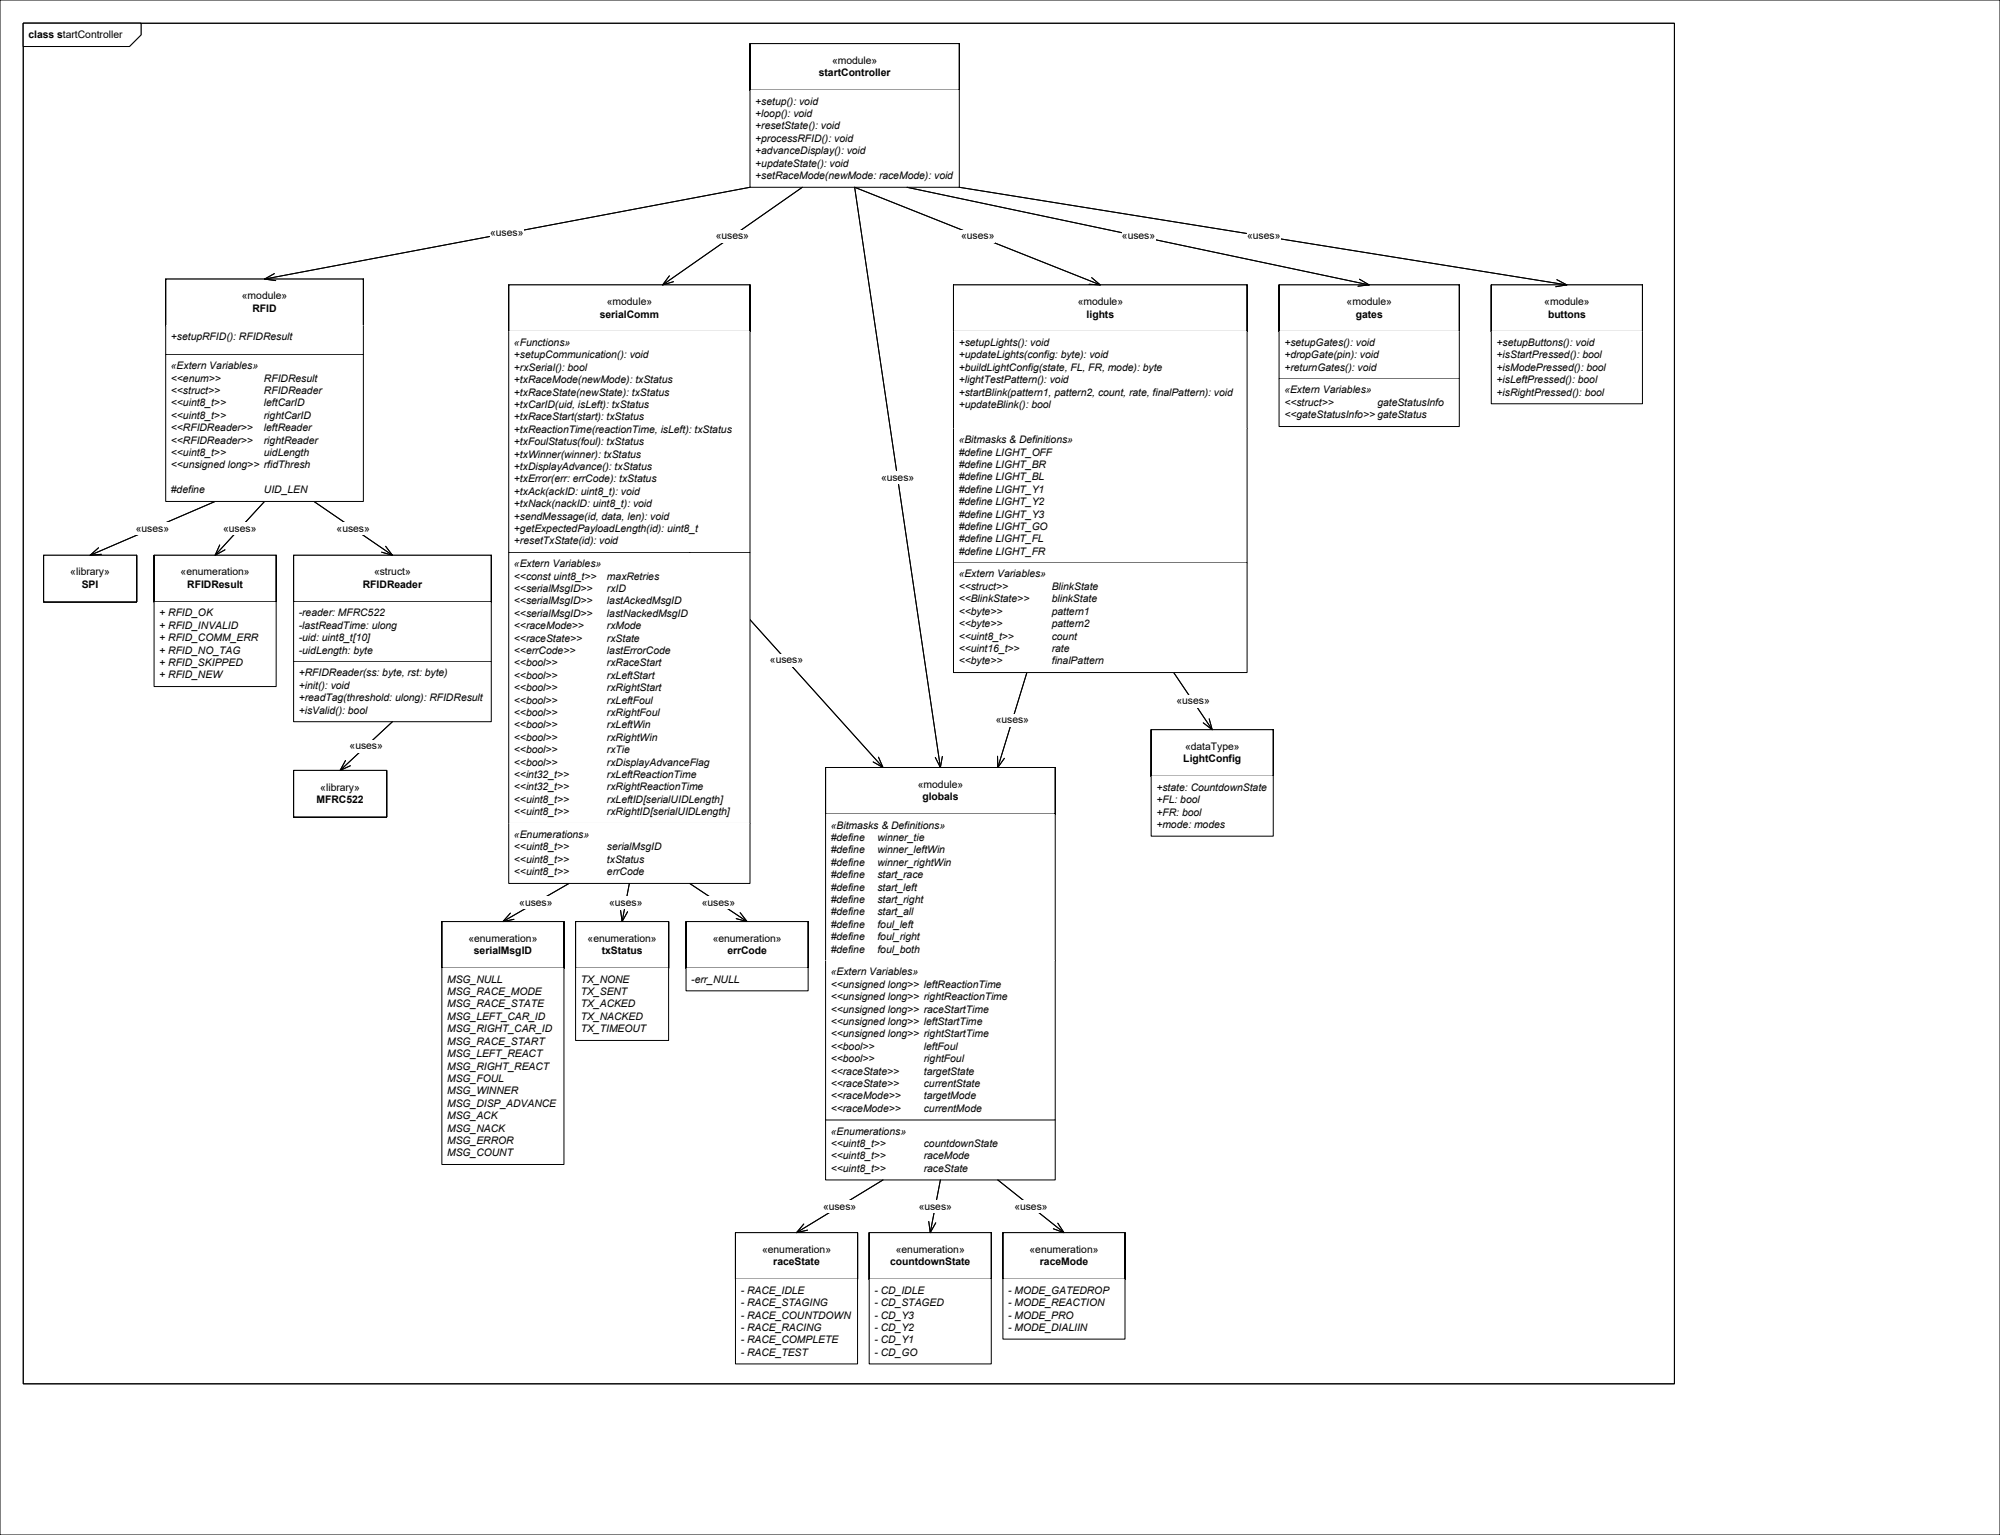
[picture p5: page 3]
«module» buttons; +setupButtons(): void +isStartPressed(): bool +isModePressed(): bool +isLeftPressed(): bool +isRightPressed(): bool; «module» gates; «module» lights; «module» serialComm; «module» globals; «Enumerations»; <<uint8_t>>; countdownState; raceMode; raceState; «module» startController; «dataType» LightConfig; +state: CountdownState +FL: bool +FR: bool +mode: modes; «uses»; «module» RFID; +setupRFID(): RFIDResult; «struct» RFIDReader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

+setup(): void
+loop(): void
+resetState(): void
+processRFID(): void
+advanceDisplay(): void
+updateState(): void
+setRaceMode(newMode: raceMode): void

«Functions»
+setupCommunication(): void
+rxSerial(): bool
+txRaceMode(newMode): txStatus
+txRaceState(newState): txStatus
+txCarID(uid, isLeft): txStatus
+txRaceStart(start): txStatus
+txReactionTime(reactionTime, isLeft): txStatus
+txFoulStatus(foul): txStatus
+txWinner(winner): txStatus
+txDisplayAdvance(): txStatus
+txError(err: errCode): txStatus
+txAck(ackID: uint8_t): void
+txNack(nackID: uint8_t): void
+sendMessage(id, data, len): void
+getExpectedPayloadLength(id): uint8_t
+resetTxState(id): void

+setupLights(): void
+updateLights(config: byte): void
+buildLightConfig(state, FL, FR, mode): byte
+lightTestPattern(): void
+startBlink(pattern1, pattern2, count, rate, finalPattern): void
+updateBlink(): bool

+setupGates(): void
+dropGate(pin): void
+returnGates(): void

«Extern Variables»
<<RFIDReader>> leftReader
<<RFIDReader>> rightReader
<<unsigned long>> rfidThresh

+RFIDReader(ss: byte, rst: byte)
+init(): void
+readTag(threshold: ulong): RFIDResult
+isValid(): bool

<<unsigned long>> leftReactionTime
<<unsigned long>> rightReactionTime
<<unsigned long>> raceStartTime
<<unsigned long>> leftStartTime
<<unsigned long>> rightStartTime

raceState = TESTING

stm startController

entry/reset(car ID, target state/mode, blink state)
entry/LIGHT_BL, LIGHT_BR
entry/returnGates
do/monitor RFID for car ID
do/tx car ID to finishController
do/rx for car ID confirmation do/monitor for state transition (btn) exit/tx state change to finishController

raceState = STAGING

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

raceState = STAGING

entry/reset(target state/mode, cdState)
do/tickCountdownState
do/handleSerial
do/check for fouls
do/update Lights
do/record start time
do/manage gate status
exit/tx state change to finishController

raceState = COUNTDOWN

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

raceState = COUNTDOWN

entry/reset(reaction time, txState, target state, foulMask)
do/check for rx race state do/calculate start/reaction times do/tx reaction times
do/tx foul status
do/manage gate status

raceState = RACING
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

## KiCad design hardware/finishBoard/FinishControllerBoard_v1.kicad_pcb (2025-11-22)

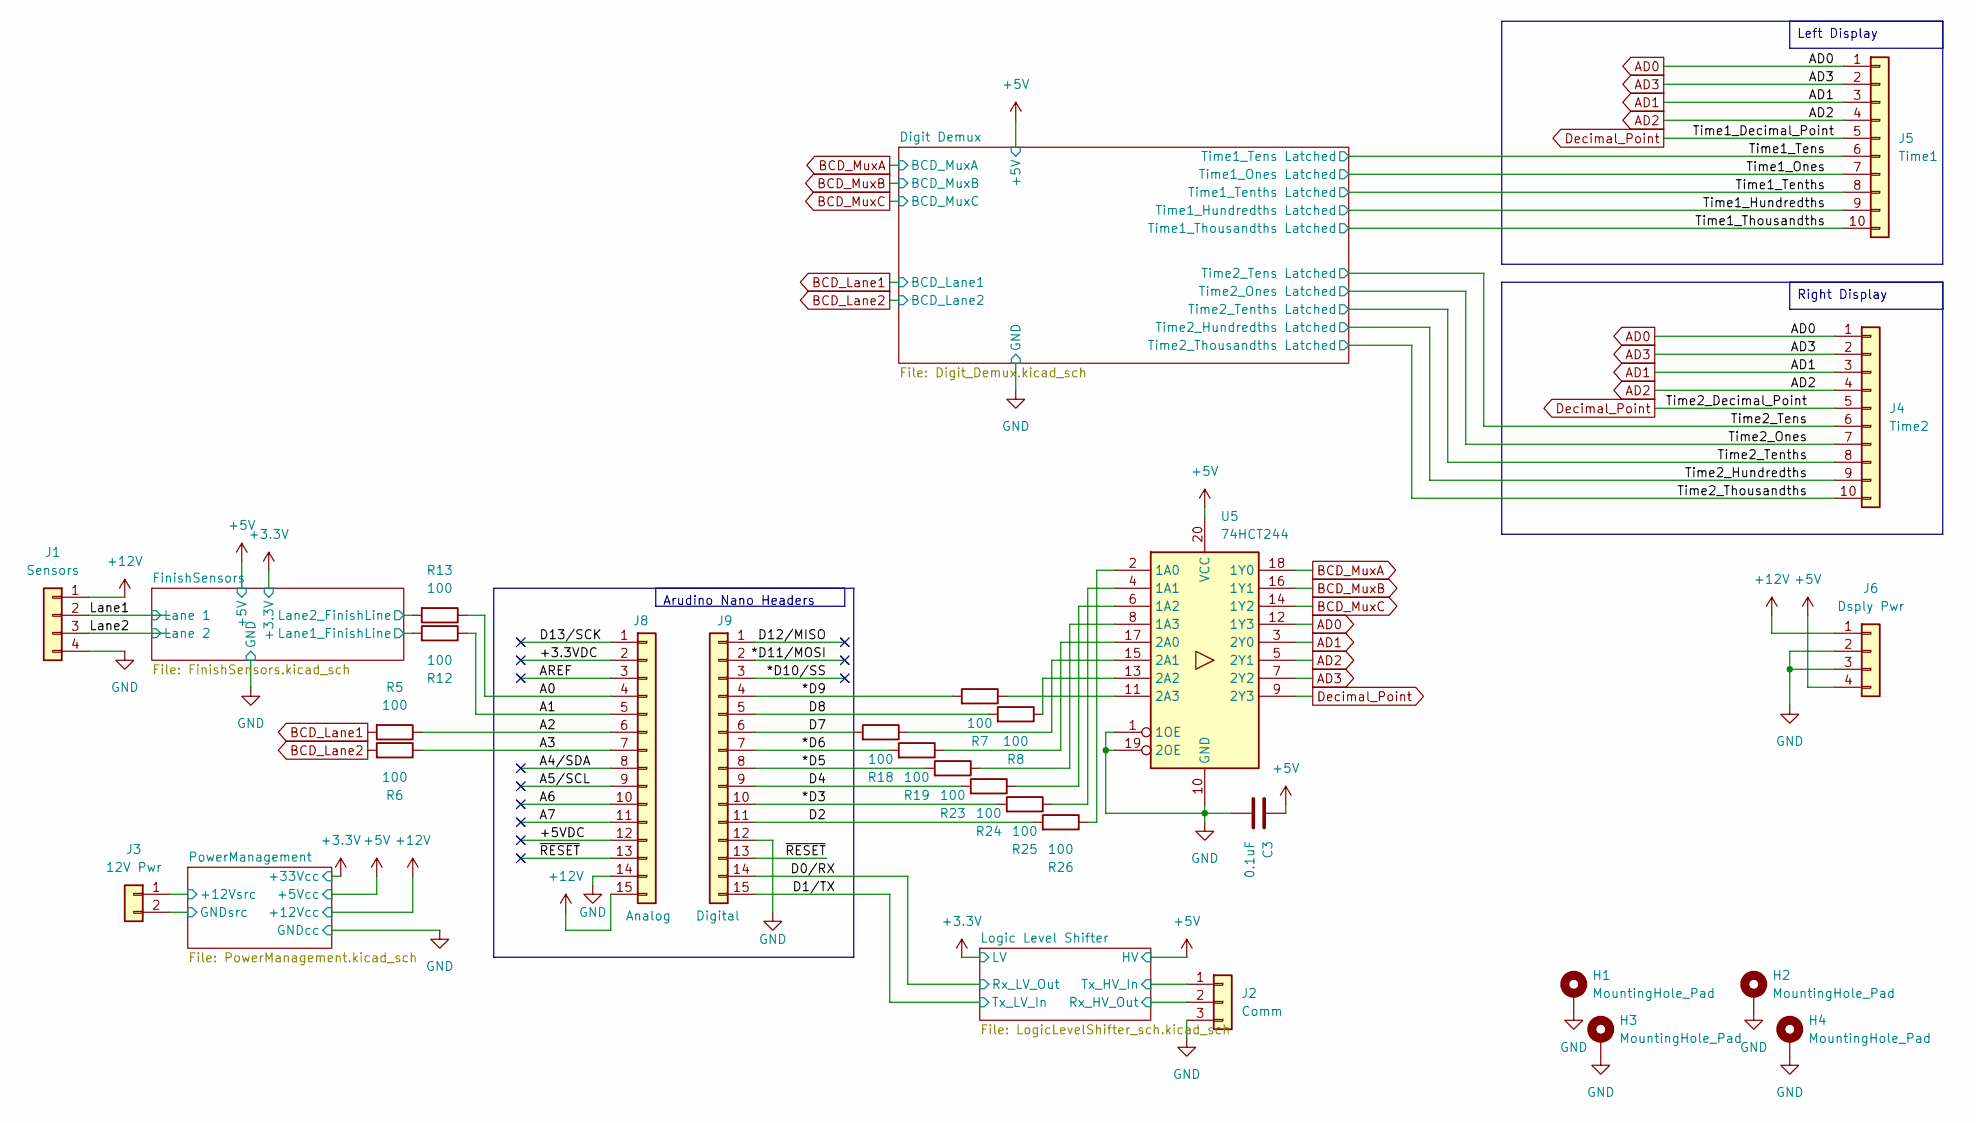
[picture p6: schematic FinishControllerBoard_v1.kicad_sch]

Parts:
C3: 0.1uF; C_0805_2012Metric
H1, H2, H3, H4: MountingHole_Pad; MountingHole_2.5mm_Pad
J1: Sensors; JST_EH_B4B-EH-A_1x04_P2.50mm_Vertical
J2: Comm; JST_EH_B3B-EH-A_1x03_P2.50mm_Vertical
J3: 12V Pwr; Molex_Nano-Fit_105309-xx02_1x02_P2.50mm_Vertical
J4: Time2; JST_EH_B10B-EH-A_1x10_P2.50mm_Vertical
J5: Time1; JST_EH_B10B-EH-A_1x10_P2.50mm_Vertical
J6: Dsply Pwr; Molex_Nano-Fit_105309-xx04_1x04_P2.50mm_Vertical
J8: Analog; PinSocket_1x15_P2.54mm_Vertical
J9: Digital; PinSocket_1x15_P2.54mm_Vertical
R5, R6, R7, R8, R12, R13, R18, R19, R23, R24, R25, R26: 100; R_0805_2012Metric
U5: 74HCT244; SOIC-20W_7.5x12.8mm_P1.27mm

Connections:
+5V: C3.1, J6.4, U5.20 (VCC); also elsewhere on the board
+12V: J1.1, J3.1, J6.1, J8.15; also elsewhere on the board
/*D3: J9.10, R25.2
/*D5: J9.8, R23.2
/*D6: J9.7, R19.2
/*D9: J9.4, R7.2
/*D10/SS: J9.3
/*D11/MOSI: J9.2
/+3.3VDC: J8.2
/+5VDC: J8.12
/A0: J8.4, R13.1
/A1: J8.5, R12.1
/A2: J8.6, R5.1
/A3: J8.7, R6.1
/A4/SDA: J8.8
/A5/SCL: J8.9
/A6: J8.10
/A7: J8.11
/AREF: J8.3
/D0/RX: J9.14; also elsewhere on the board
/D1/TX: J9.15; also elsewhere on the board
/D2: J9.11, R26.2
/D4: J9.9, R24.2
/D7: J9.6, R18.2
/D8: J9.5, R8.2
/D12/MISO: J9.1
/D13/SCK: J8.1
/FinishSensors/Lane1_FinishLine: R12.2; also elsewhere on the board
/FinishSensors/Lane2_FinishLine: R13.2; also elsewhere on the board
/Lane1: J1.2; also elsewhere on the board
/Lane2: J1.3; also elsewhere on the board
/Logic Level Shifter/Rx_HV_Out: J2.2; also elsewhere on the board
/Logic Level Shifter/Tx_HV_In: J2.1; also elsewhere on the board
/Time1_Hundredths: J5.9; also elsewhere on the board
/Time1_Ones: J5.7; also elsewhere on the board
/Time1_Tens: J5.6; also elsewhere on the board
/Time1_Tenths: J5.8; also elsewhere on the board
/Time1_Thousandths: J5.10; also elsewhere on the board
/Time2_Hundredths: J4.9; also elsewhere on the board
/Time2_Ones: J4.7; also elsewhere on the board
/Time2_Tens: J4.6; also elsewhere on the board
/Time2_Tenths: J4.8; also elsewhere on the board
/Time2_Thousandths: J4.10; also elsewhere on the board
/~RESET: J8.13, J9.13
AD0: J4.1, J5.1, U5.12 (1Y3)
AD1: J4.3, J5.3, U5.3 (2Y0)
AD2: J4.4, J5.4, U5.5 (2Y1)
AD3: J4.2, J5.2, U5.7 (2Y2)
BCD_Lane1: R5.2; also elsewhere on the board
BCD_Lane2: R6.2; also elsewhere on the board
BCD_MuxA: U5.18 (1Y0); also elsewhere on the board
BCD_MuxB: U5.16 (1Y1); also elsewhere on the board
BCD_MuxC: U5.14 (1Y2); also elsewhere on the board
Decimal_Point: J4.5, J5.5, U5.9 (2Y3)
GND: C3.2, H1.1, H2.1, H3.1, H4.1, J1.4, J2.3, J3.2, J6.2, J6.3, J8.14, J9.12, U5.1 (1OE), U5.10 (GND), U5.19 (2OE); also elsewhere on the board
unnamed: R26.1, U5.2 (1A0)
unnamed: R25.1, U5.4 (1A1)
unnamed: R24.1, U5.6 (1A2)
unnamed: R23.1, U5.8 (1A3)
unnamed: R19.1, U5.17 (2A0)
unnamed: R18.1, U5.15 (2A1)
unnamed: R8.1, U5.13 (2A2)
unnamed: R7.1, U5.11 (2A3)

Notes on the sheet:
Arudino Nano Headers
Right Display
Left Display

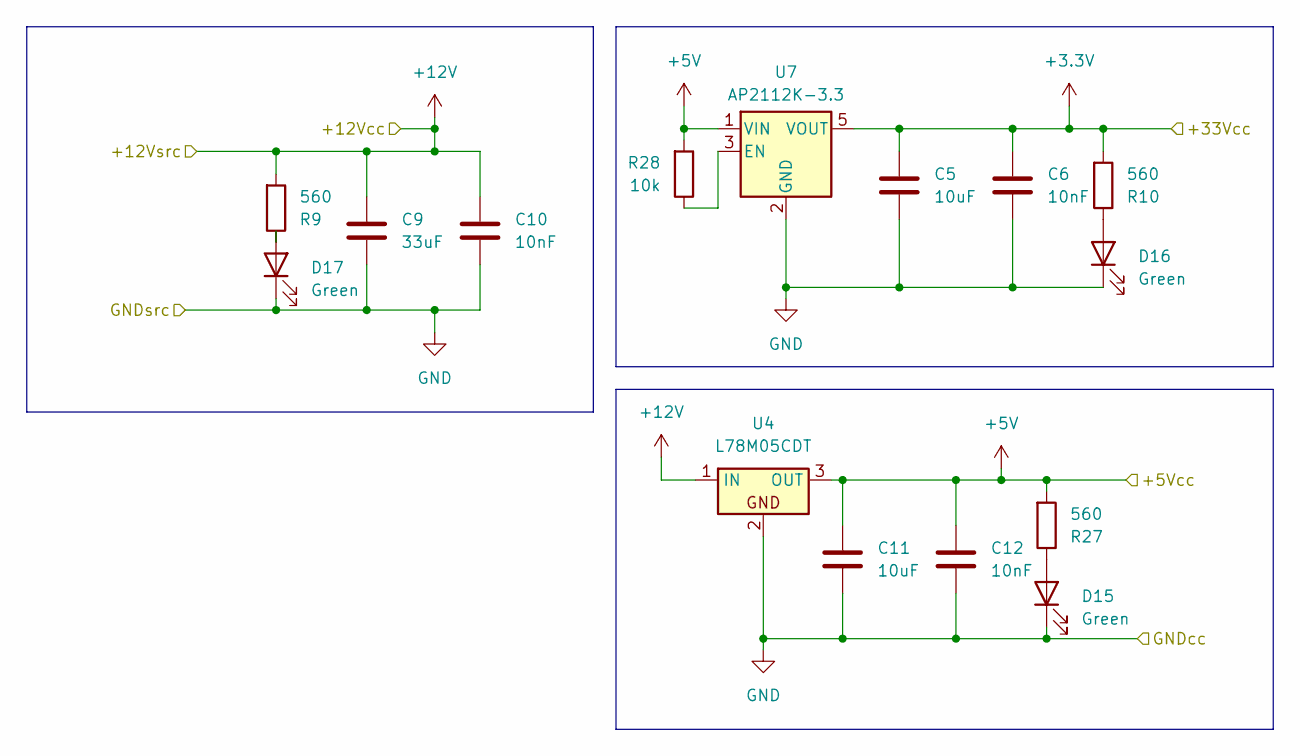
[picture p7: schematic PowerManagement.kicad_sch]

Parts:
C5, C11: 10uF; C_0805_2012Metric
C6, C10, C12: 10nF; C_0805_2012Metric
C9: 33uF; C_Elec_6.3x7.7
D15, D16, D17: Green; LED_0805_2012Metric_Pad1.15x1.40mm_HandSolder
R9, R10, R27: 560; R_0805_2012Metric
R28: 10k; R_0805_2012Metric
U4: L78M05CDT; TO-252-2
U7: AP2112K-3.3; SOT-23-5_HandSoldering

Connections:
+3.3V: C5.1, C6.1, R10.2, U7.5 (VOUT); also elsewhere on the board
+5V: C11.1, C12.1, R27.2, R28.2, U4.3 (OUT), U7.1 (VIN); also elsewhere on the board
+12V: C9.1, C10.1, R9.2, U4.1 (IN); also elsewhere on the board
GND: C5.2, C6.2, C9.2, C10.2, C11.2, C12.2, D15.1 (K), D16.1 (K), D17.1 (K), U4.2, U7.2 (GND); also elsewhere on the board
unnamed: D15.2 (A), R27.1
unnamed: D16.2 (A), R10.1
unnamed: D17.2 (A), R9.1
unnamed: R28.1, U7.3 (EN)

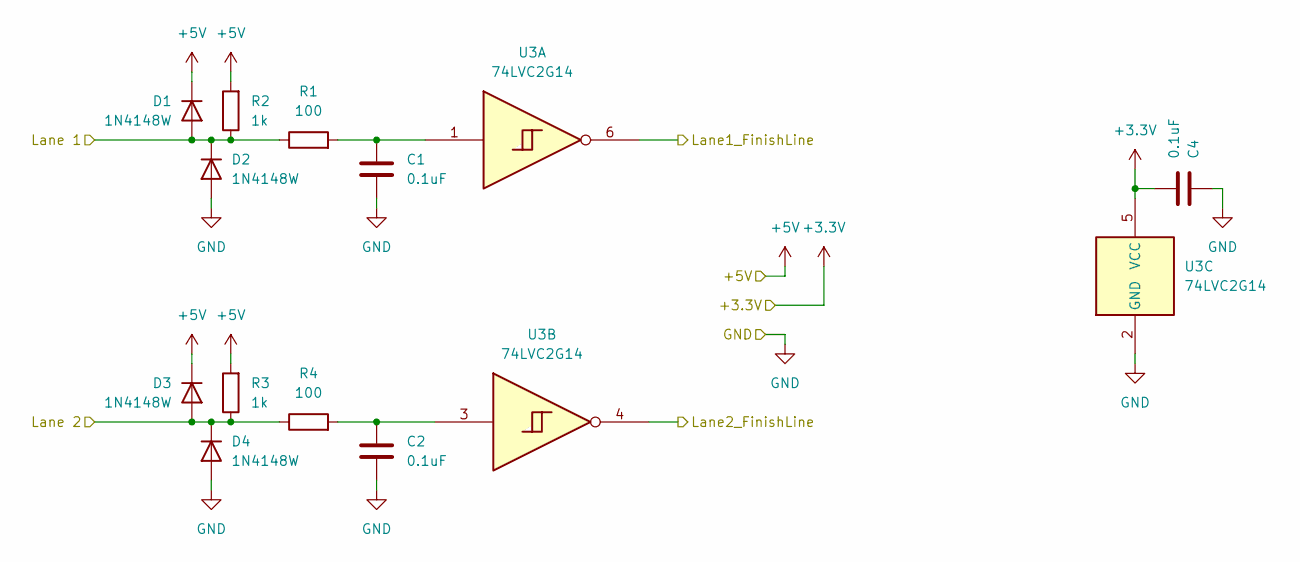
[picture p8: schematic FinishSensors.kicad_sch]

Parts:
C1, C2, C4: 0.1uF; C_0805_2012Metric
D1, D2, D3, D4: 1N4148W; D_SOD-123
R1, R4: 100; R_0805_2012Metric
R2, R3: 1k; R_0805_2012Metric
U3: 74LVC2G14; SOT-23-6_Handsoldering

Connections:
+3.3V: C4.2, U3.5 (VCC); also elsewhere on the board
+5V: D1.1 (K), D3.1 (K), R2.2, R3.2; also elsewhere on the board
/FinishSensors/Lane1_FinishLine: U3.6; also elsewhere on the board
/FinishSensors/Lane2_FinishLine: U3.4; also elsewhere on the board
/Lane1: D1.2 (A), D2.1 (K), R1.1, R2.1; also elsewhere on the board
/Lane2: D3.2 (A), D4.1 (K), R3.1, R4.1; also elsewhere on the board
GND: C1.2, C2.2, C4.1, D2.2 (A), D4.2 (A), U3.2 (GND); also elsewhere on the board
unnamed: C1.1, R1.2, U3.1
unnamed: C2.1, R4.2, U3.3

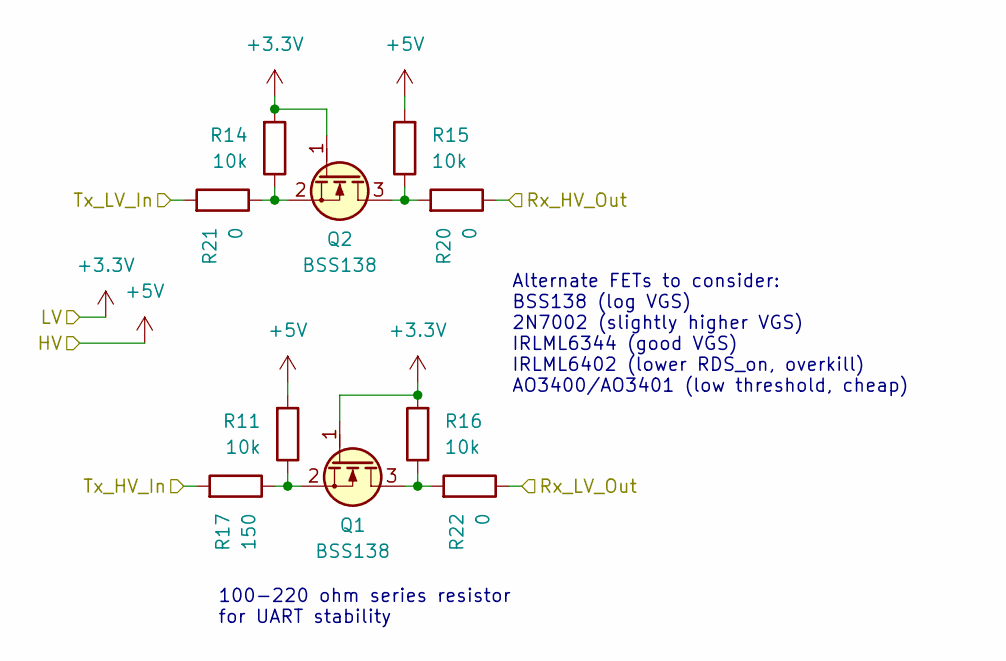
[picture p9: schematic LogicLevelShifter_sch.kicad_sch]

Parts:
Q1, Q2: BSS138; SOT-23_Handsoldering
R11, R14, R15, R16: 10k; R_0805_2012Metric
R17: 150; R_0805_2012Metric
R20, R21, R22: 0; R_0805_2012Metric

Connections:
+3.3V: Q1.1 (G), Q2.1 (G), R14.2, R16.2; also elsewhere on the board
+5V: R11.2, R15.2; also elsewhere on the board
/D0/RX: R22.1; also elsewhere on the board
/D1/TX: R21.2; also elsewhere on the board
/Logic Level Shifter/Rx_HV_Out: R20.1; also elsewhere on the board
/Logic Level Shifter/Tx_HV_In: R17.2; also elsewhere on the board
unnamed: Q1.3 (D), R16.1, R22.2
unnamed: Q1.2 (S), R11.1, R17.1
unnamed: Q2.3 (D), R15.1, R20.2
unnamed: Q2.2 (S), R14.1, R21.1

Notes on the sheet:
100-220 ohm series resistor for UART stability
Alternate FETs to consider: BSS138 (log VGS) 2N7002 (slightly higher VGS) IRLML6344 (good VGS) IRLML6402 (lower RDS_on, overkill) AO3400/AO3401 (low threshold, cheap)

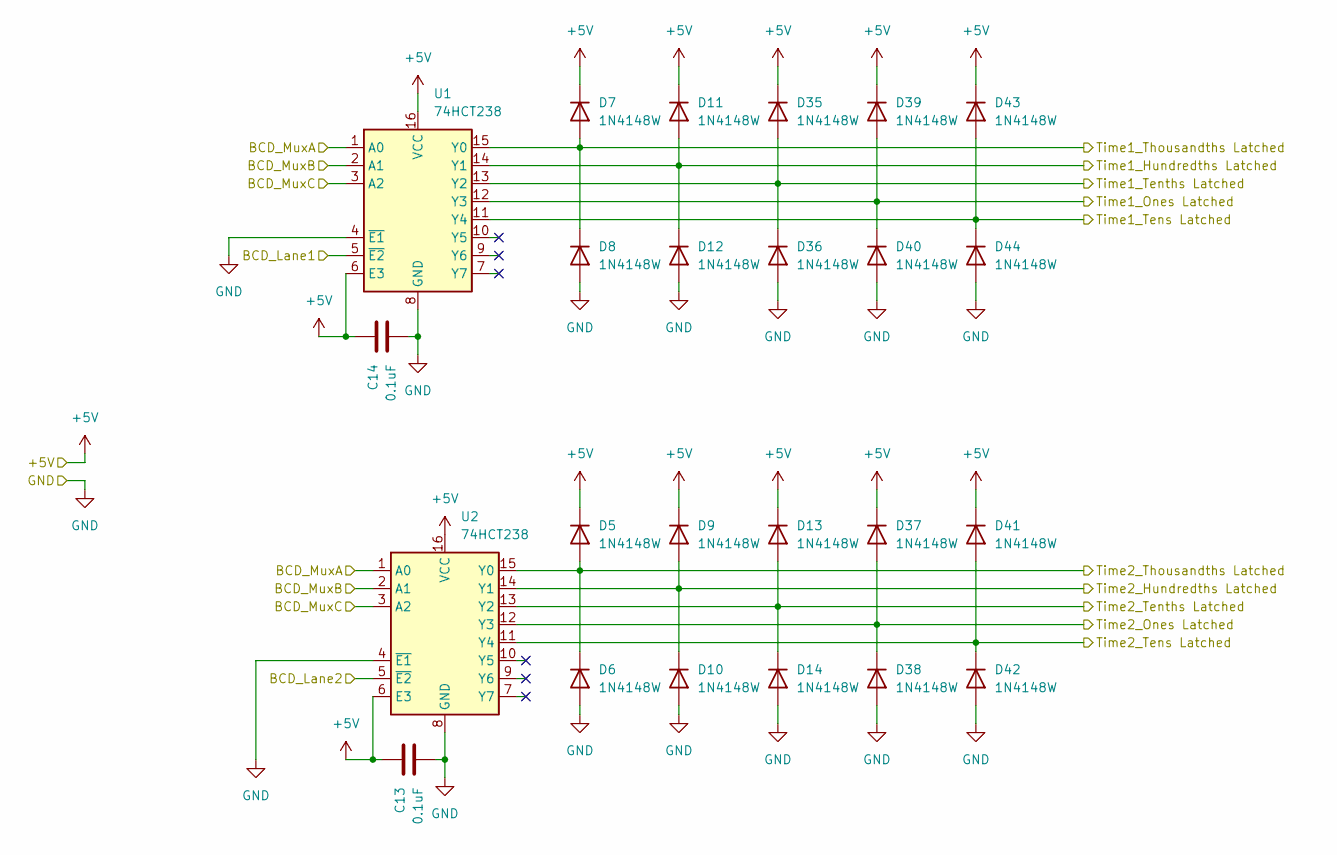
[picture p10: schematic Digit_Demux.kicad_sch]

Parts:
C13, C14: 0.1uF; C_0805_2012Metric
D5, D6, D7, D8, D9, D10, D11, D12, D13, D14, D35, D36, D37, D38, D39, D40, D41, D42, D43, D44: 1N4148W; D_SOD-123
U1, U2: 74HCT238; SOIC-16_3.9x9.9mm_P1.27mm

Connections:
+5V: C13.1, C14.1, D5.1 (K), D7.1 (K), D9.1 (K), D11.1 (K), D13.1 (K), D35.1 (K), D37.1 (K), D39.1 (K), D41.1 (K), D43.1 (K), U1.6 (E3), U1.16 (VCC), U2.6 (E3), U2.16 (VCC); also elsewhere on the board
/Time1_Hundredths: D11.2 (A), D12.1 (K), U1.14 (Y1); also elsewhere on the board
/Time1_Ones: D39.2 (A), D40.1 (K), U1.12 (Y3); also elsewhere on the board
/Time1_Tens: D43.2 (A), D44.1 (K), U1.11 (Y4); also elsewhere on the board
/Time1_Tenths: D35.2 (A), D36.1 (K), U1.13 (Y2); also elsewhere on the board
/Time1_Thousandths: D7.2 (A), D8.1 (K), U1.15 (Y0); also elsewhere on the board
/Time2_Hundredths: D9.2 (A), D10.1 (K), U2.14 (Y1); also elsewhere on the board
/Time2_Ones: D37.2 (A), D38.1 (K), U2.12 (Y3); also elsewhere on the board
/Time2_Tens: D41.2 (A), D42.1 (K), U2.11 (Y4); also elsewhere on the board
/Time2_Tenths: D13.2 (A), D14.1 (K), U2.13 (Y2); also elsewhere on the board
/Time2_Thousandths: D5.2 (A), D6.1 (K), U2.15 (Y0); also elsewhere on the board
BCD_Lane1: U1.5 (~E2); also elsewhere on the board
BCD_Lane2: U2.5 (~E2); also elsewhere on the board
BCD_MuxA: U1.1 (A0), U2.1 (A0); also elsewhere on the board
BCD_MuxB: U1.2 (A1), U2.2 (A1); also elsewhere on the board
BCD_MuxC: U1.3 (A2), U2.3 (A2); also elsewhere on the board
GND: C13.2, C14.2, D6.2 (A), D8.2 (A), D10.2 (A), D12.2 (A), D14.2 (A), D36.2 (A), D38.2 (A), D40.2 (A), D42.2 (A), D44.2 (A), U1.4 (~E1), U1.8 (GND), U2.4 (~E1), U2.8 (GND); also elsewhere on the board

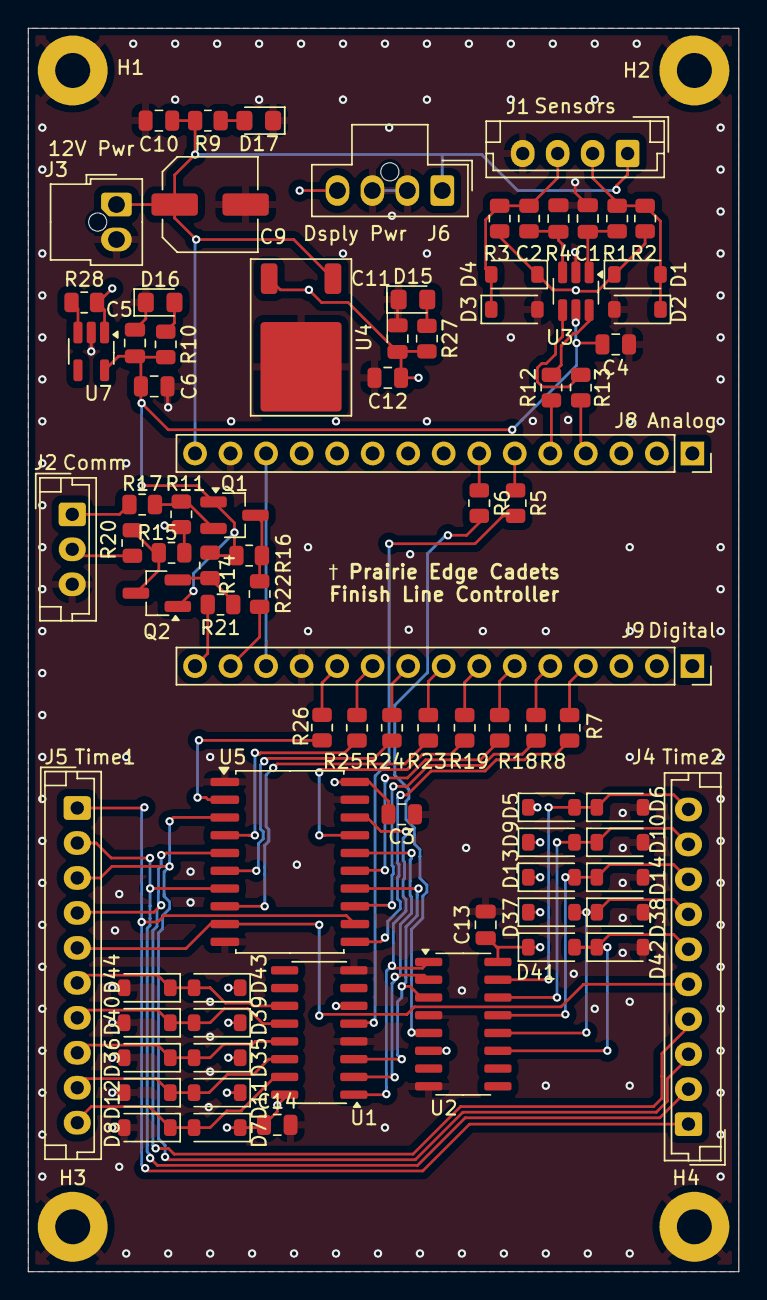
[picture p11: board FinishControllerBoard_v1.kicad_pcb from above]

Board: 4 copper layers, 50.8 x 88.9 mm, 87 parts (0 on the bottom side), 63 nets.

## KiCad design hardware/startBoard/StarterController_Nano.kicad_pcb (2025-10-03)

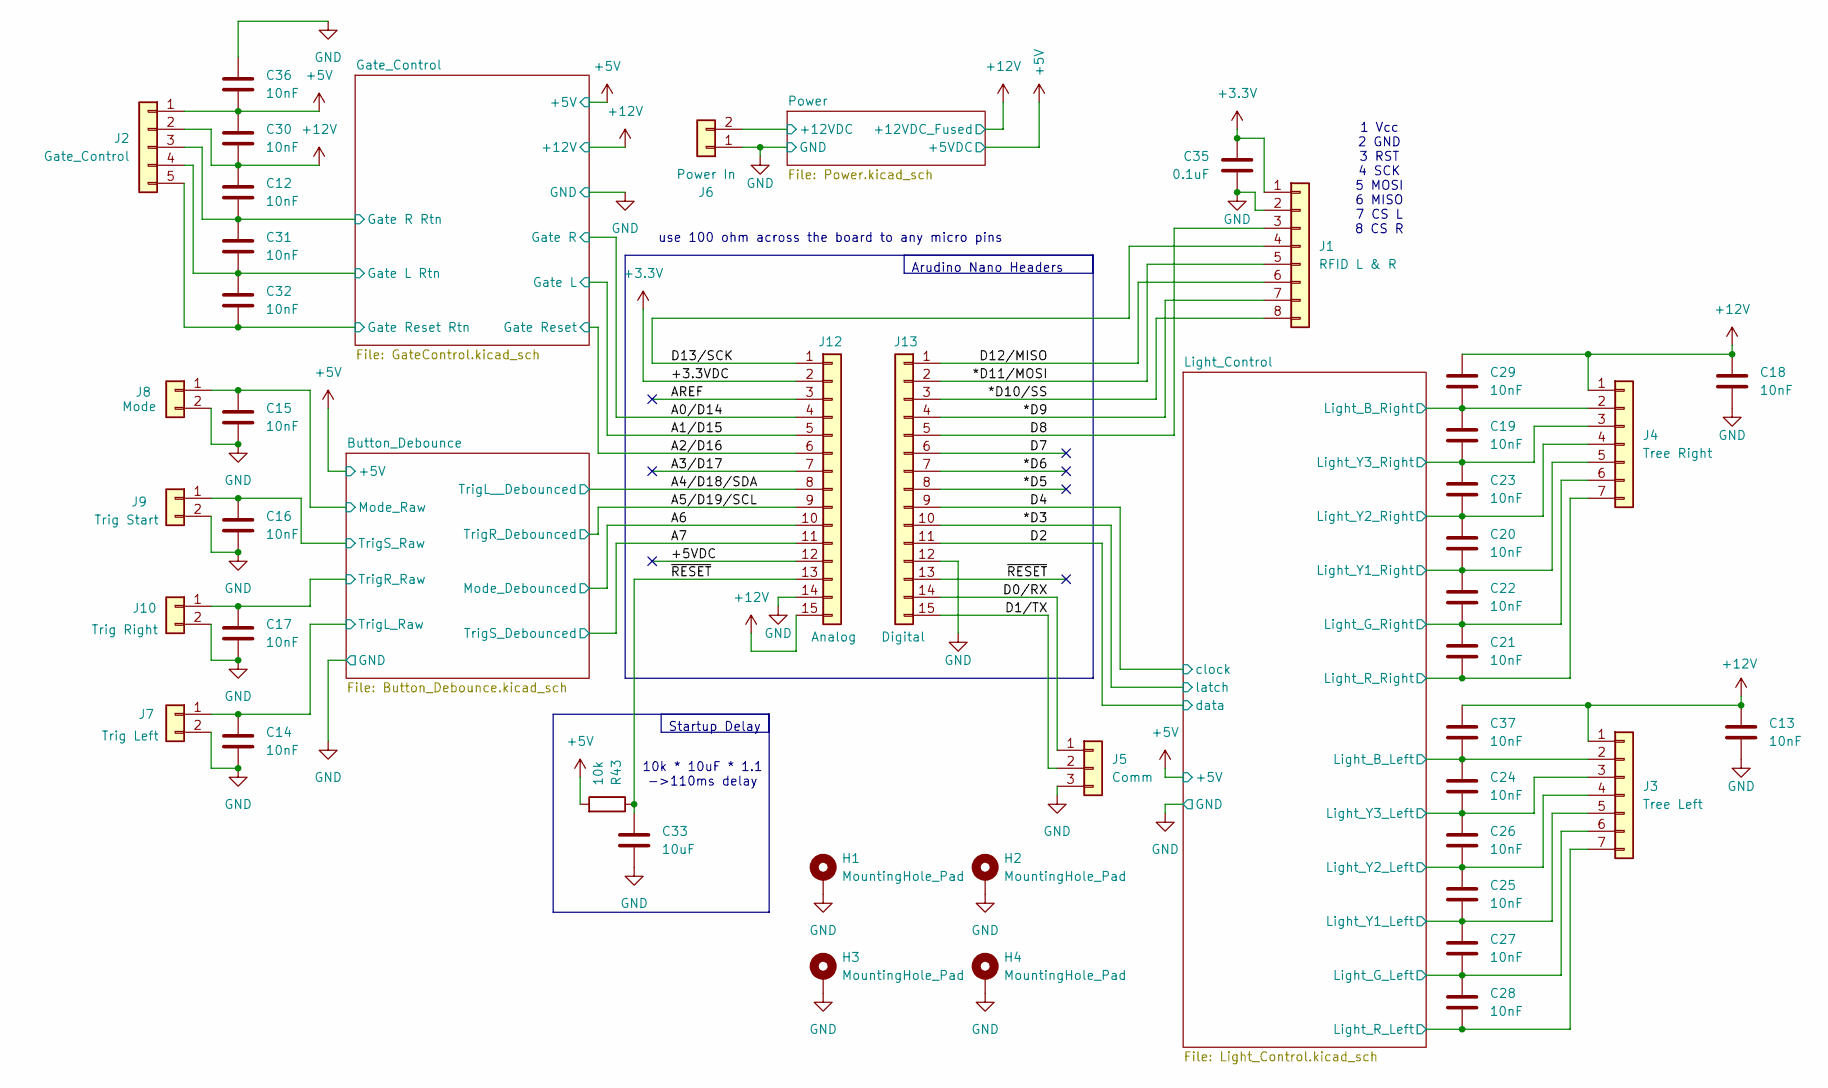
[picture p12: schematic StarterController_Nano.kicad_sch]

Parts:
C12, C13, C14, C15, C16, C17, C18, C19, C20, C21, C22, C23, C24, C25, C26, C27, C28, C29, C30, C31, C32, C36, C37: 10nF; C_0805_2012Metric
C33: 10uF; C_0805_2012Metric
C35: 0.1uF; C_0805_2012Metric
H1, H2, H3, H4: MountingHole_Pad; MountingHole_2.5mm_Pad
J1: RFID L & R; JST_EH_B8B-EH-A_1x08_P2.50mm_Vertical
J2: Gate_Control; JST_EH_B5B-EH-A_1x05_P2.50mm_Vertical
J3: Tree Left; JST_EH_B7B-EH-A_1x07_P2.50mm_Vertical
J4: Tree Right; JST_EH_B7B-EH-A_1x07_P2.50mm_Vertical
J5: Comm; JST_EH_B3B-EH-A_1x03_P2.50mm_Vertical
J6: Power In; Molex_Nano-Fit_105309-xx02_1x02_P2.50mm_Vertical
J7: Trig Left; JST_EH_B2B-EH-A_1x02_P2.50mm_Vertical
J8: Mode; JST_EH_B2B-EH-A_1x02_P2.50mm_Vertical
J9: Trig Start; JST_EH_B2B-EH-A_1x02_P2.50mm_Vertical
J10: Trig Right; JST_EH_B2B-EH-A_1x02_P2.50mm_Vertical
J12: Analog; PinSocket_1x15_P2.54mm_Vertical
J13: Digital; PinSocket_1x15_P2.54mm_Vertical
R43: 10k; R_0805_2012Metric

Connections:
+3.3V: C35.1, J1.1, J12.2
+5V: C30.1, C36.2, J2.1, R43.2; also elsewhere on the board
+12V: C12.1, C13.1, C18.1, C29.1, C30.2, C37.1, J2.2, J3.1, J4.1, J12.15; also elsewhere on the board
/*D3: J13.10; also elsewhere on the board
/*D5: J13.8
/*D6: J13.7
/*D9: J1.7, J13.4
/*D10/SS: J1.8, J13.3
/*D11/MOSI: J1.5, J13.2
/+5VDC: J12.12
/A0: J12.4; also elsewhere on the board
/A1: J12.5; also elsewhere on the board
/A2: J12.6; also elsewhere on the board
/A3: J12.7
/A4/SDA: J12.8; also elsewhere on the board
/A5/SCL: J12.9; also elsewhere on the board
/A6: J12.10; also elsewhere on the board
/A7: J12.11; also elsewhere on the board
/AREF: J12.3
/Button_Debounce/Mode_Raw: C15.1, J8.1; also elsewhere on the board
/Button_Debounce/TrigL_Raw: C14.1, J7.1; also elsewhere on the board
/Button_Debounce/TrigR_Raw: C17.1, J10.1; also elsewhere on the board
/Button_Debounce/TrigS_Raw: C16.1, J9.1; also elsewhere on the board
/D0/RX: J5.1, J13.14
/D1/TX: J5.2, J13.15
/D2: J13.11; also elsewhere on the board
/D4: J13.9; also elsewhere on the board
/D7: J13.6
/D8: J1.3, J13.5
/D12/MISO: J1.6, J13.1
/D13/SCK: J1.4, J12.1
/Gate_Control/Gate L Rtn: C31.2, C32.1, J2.4; also elsewhere on the board
/Gate_Control/Gate R Rtn: C12.2, C31.1, J2.3; also elsewhere on the board
/Gate_Control/Gate Reset Rtn: C32.2, J2.5; also elsewhere on the board
/Light_Control/Light_B_Left: C24.1, C37.2, J3.2; also elsewhere on the board
/Light_Control/Light_B_Right: C19.1, C29.2, J4.2; also elsewhere on the board
/Light_Control/Light_G_Left: C27.2, C28.1, J3.6; also elsewhere on the board
/Light_Control/Light_G_Right: C21.1, C22.2, J4.6; also elsewhere on the board
/Light_Control/Light_R_Left: C28.2, J3.7; also elsewhere on the board
/Light_Control/Light_R_Right: C21.2, J4.7; also elsewhere on the board
/Light_Control/Light_Y1_Left: C25.2, C27.1, J3.5; also elsewhere on the board
/Light_Control/Light_Y1_Right: C20.2, C22.1, J4.5; also elsewhere on the board
/Light_Control/Light_Y2_Left: C25.1, C26.2, J3.4; also elsewhere on the board
/Light_Control/Light_Y2_Right: C20.1, C23.2, J4.4; also elsewhere on the board
/Light_Control/Light_Y3_Left: C24.2, C26.1, J3.3; also elsewhere on the board
/Light_Control/Light_Y3_Right: C19.2, C23.1, J4.3; also elsewhere on the board
/Power/+12VDC: J6.2; also elsewhere on the board
/~RESET: C33.1, J12.13, J13.13, R43.1
GND: C13.2, C14.2, C15.2, C16.2, C17.2, C18.2, C33.2, C35.2, C36.1, H1.1, H2.1, H3.1, H4.1, J1.2, J5.3, J6.1, J7.2, J8.2, J9.2, J10.2, J12.14, J13.12; also elsewhere on the board

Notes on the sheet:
1 Vcc 2 GND 3 RST 4 SCK 5 MOSI 6 MISO 7 CS L 8 CS R
10k * 10uF * 1.1 ->110ms delay
use 100 ohm across the board to any micro pins
Arudino Nano Headers
Startup Delay

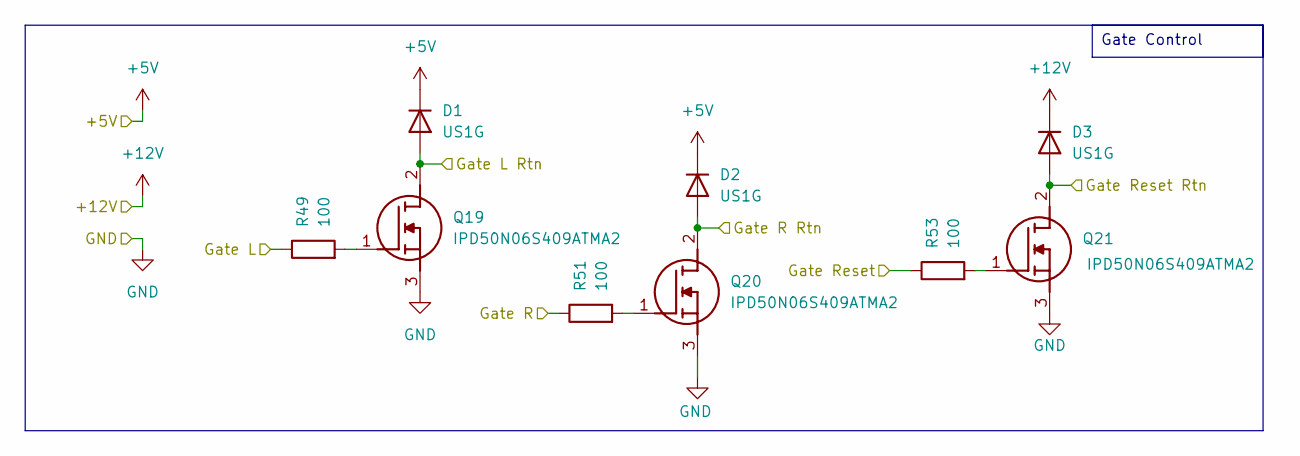
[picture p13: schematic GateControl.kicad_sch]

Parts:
D1, D2, D3: US1G; D_SMA
Q19, Q20, Q21: IPD50N06S409ATMA2; TO-252-3_TabPin2; Mouser Part Number 726-IPD50N06S409ATMA
R49, R51, R53: 100; R_0805_2012Metric

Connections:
+5V: D1.1 (K), D2.1 (K); also elsewhere on the board
+12V: D3.1 (K); also elsewhere on the board
/A0: R51.1; also elsewhere on the board
/A1: R49.1; also elsewhere on the board
/A2: R53.1; also elsewhere on the board
/Gate_Control/Gate L Rtn: D1.2 (A), Q19.2 (D); also elsewhere on the board
/Gate_Control/Gate R Rtn: D2.2 (A), Q20.2 (D); also elsewhere on the board
/Gate_Control/Gate Reset Rtn: D3.2 (A), Q21.2 (D); also elsewhere on the board
GND: Q19.3 (S), Q20.3 (S), Q21.3 (S); also elsewhere on the board
unnamed: Q19.1 (G), R49.2
unnamed: Q20.1 (G), R51.2
unnamed: Q21.1 (G), R53.2

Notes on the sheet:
Gate Control

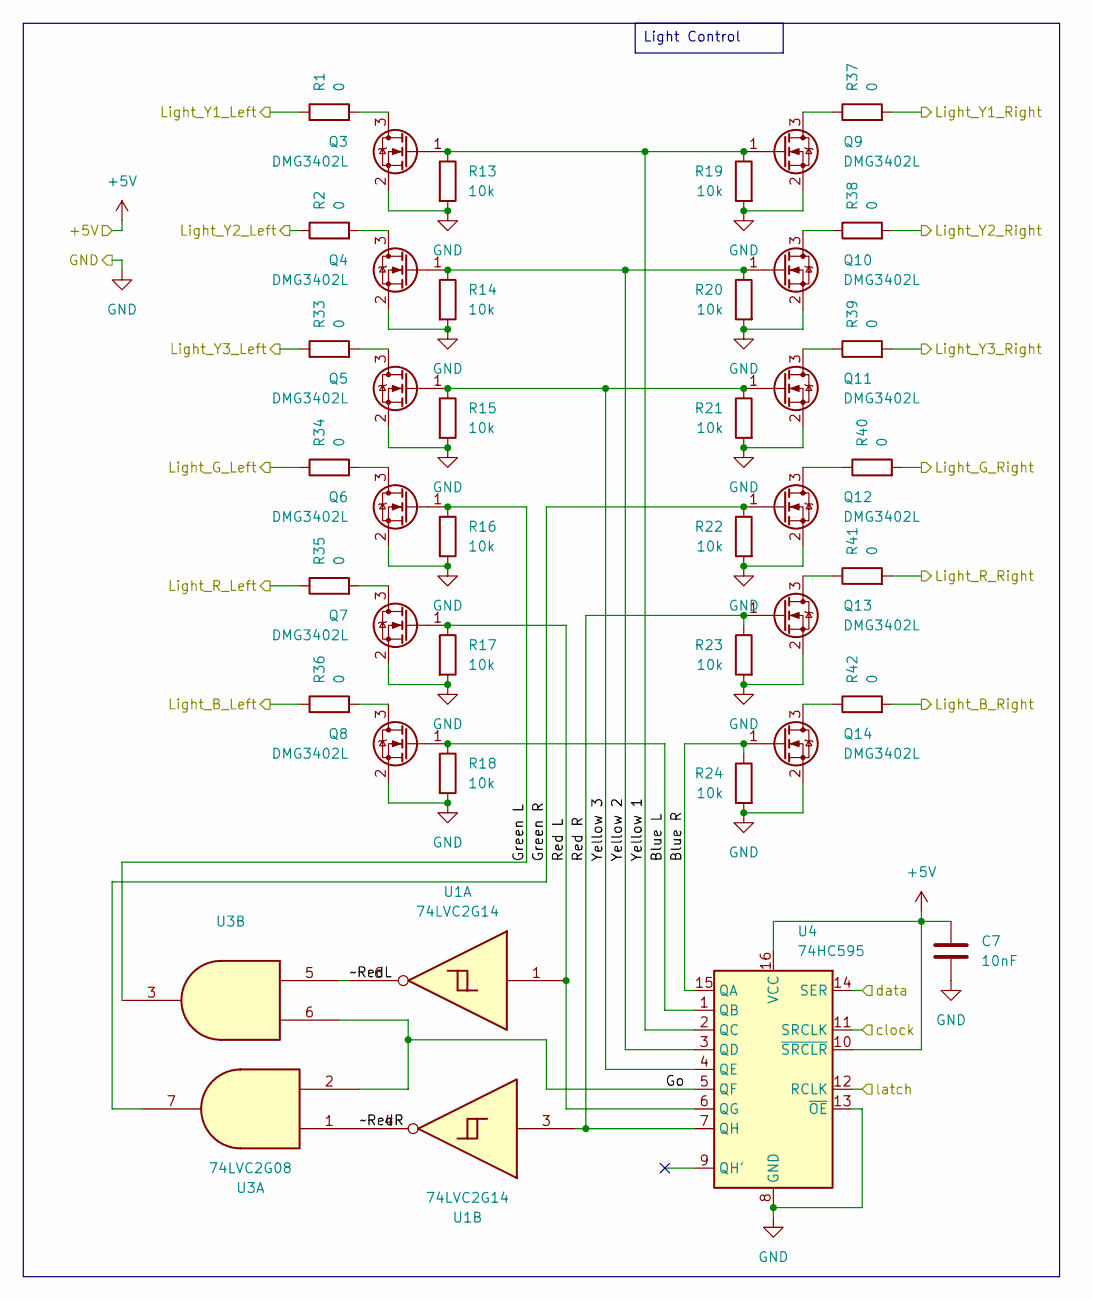
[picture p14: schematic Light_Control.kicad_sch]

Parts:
C7: 10nF; C_0805_2012Metric
Q3, Q4, Q5, Q6, Q7, Q8, Q9, Q10, Q11, Q12, Q13, Q14: DMG3402L; SOT-23-3
R1, R2, R33, R34, R35, R36, R37, R38, R39, R40, R41, R42: 0; R_0805_2012Metric
R13, R14, R15, R16, R17, R18, R19, R20, R21, R22, R23, R24: 10k; R_0805_2012Metric
U1: 74LVC2G14; SOT-363_SC-70-6
U3: 74LVC2G08; SSOP-8_2.95x2.8mm_P0.65mm
U4: 74HC595; SOIC-16_3.9x9.9mm_P1.27mm

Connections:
+5V: C7.1, U4.10 (~SRCLR), U4.16 (VCC); also elsewhere on the board
/*D3: U4.12 (RCLK); also elsewhere on the board
/D2: U4.14 (SER); also elsewhere on the board
/D4: U4.11 (SRCLK); also elsewhere on the board
/Light_Control/Blue L: Q8.1 (G), R18.1, U4.1 (QB)
/Light_Control/Blue R: Q14.1 (G), R24.1, U4.15 (QA)
/Light_Control/Go: U3.2, U3.6, U4.5 (QF)
/Light_Control/Green L: Q6.1 (G), R16.1, U3.3
/Light_Control/Green R: Q12.1 (G), R22.1, U3.7
/Light_Control/Light_B_Left: R36.1; also elsewhere on the board
/Light_Control/Light_B_Right: R42.2; also elsewhere on the board
/Light_Control/Light_G_Left: R34.1; also elsewhere on the board
/Light_Control/Light_G_Right: R40.2; also elsewhere on the board
/Light_Control/Light_R_Left: R35.1; also elsewhere on the board
/Light_Control/Light_R_Right: R41.2; also elsewhere on the board
/Light_Control/Light_Y1_Left: R1.1; also elsewhere on the board
/Light_Control/Light_Y1_Right: R37.2; also elsewhere on the board
/Light_Control/Light_Y2_Left: R2.1; also elsewhere on the board
/Light_Control/Light_Y2_Right: R38.2; also elsewhere on the board
/Light_Control/Light_Y3_Left: R33.1; also elsewhere on the board
/Light_Control/Light_Y3_Right: R39.2; also elsewhere on the board
/Light_Control/Red L: Q7.1 (G), R17.1, U1.1, U4.6 (QG)
/Light_Control/Red R: Q13.1 (G), R23.1, U1.3, U4.7 (QH)
/Light_Control/Yellow 1: Q3.1 (G), Q9.1 (G), R13.1, R19.1, U4.2 (QC)
/Light_Control/Yellow 2: Q4.1 (G), Q10.1 (G), R14.1, R20.1, U4.3 (QD)
/Light_Control/Yellow 3: Q5.1 (G), Q11.1 (G), R15.1, R21.1, U4.4 (QE)
/Light_Control/~RedL: U1.6, U3.5
/Light_Control/~RedR: U1.4, U3.1
GND: C7.2, Q3.2 (S), Q4.2 (S), Q5.2 (S), Q6.2 (S), Q7.2 (S), Q8.2 (S), Q9.2 (S), Q10.2 (S), Q11.2 (S), Q12.2 (S), Q13.2 (S), Q14.2 (S), R13.2, R14.2, R15.2, R16.2, R17.2, R18.2, R19.2, R20.2, R21.2, R22.2, R23.2, R24.2, U4.8 (GND), U4.13 (~OE); also elsewhere on the board
unnamed: Q3.3 (D), R1.2
unnamed: Q4.3 (D), R2.2
unnamed: Q5.3 (D), R33.2
unnamed: Q6.3 (D), R34.2
unnamed: Q7.3 (D), R35.2
unnamed: Q8.3 (D), R36.2
unnamed: Q9.3 (D), R37.1
unnamed: Q10.3 (D), R38.1
unnamed: Q11.3 (D), R39.1
unnamed: Q12.3 (D), R40.1
unnamed: Q13.3 (D), R41.1
unnamed: Q14.3 (D), R42.1

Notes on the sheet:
Light Control

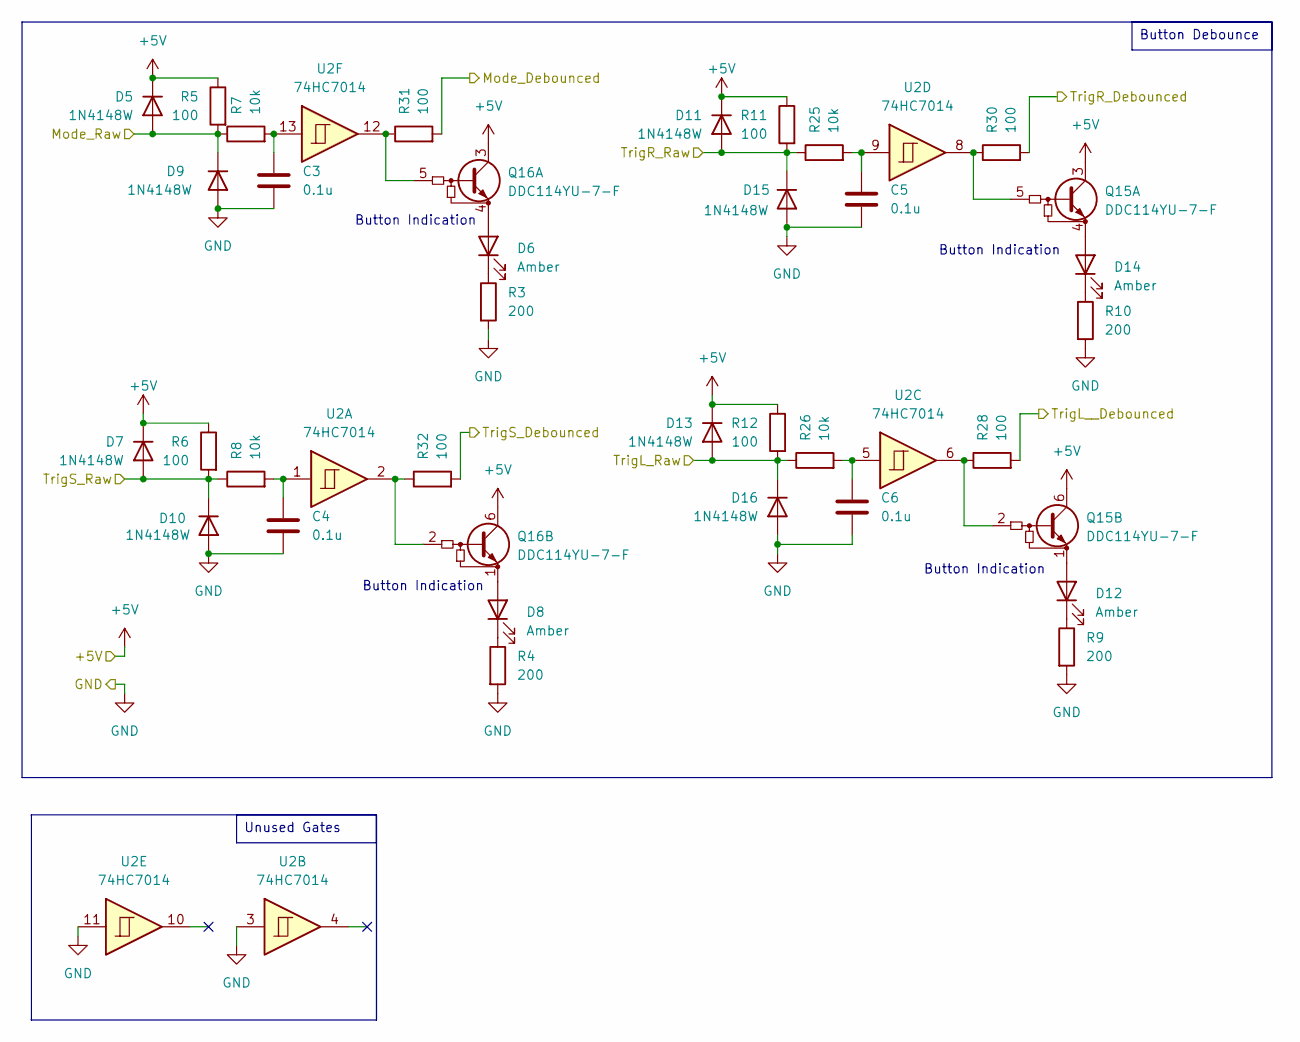
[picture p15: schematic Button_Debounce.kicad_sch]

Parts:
C3, C4, C5, C6: 0.1u; C_0805_2012Metric
D5, D7, D9, D10, D11, D13, D15, D16: 1N4148W; D_SOD-123
D6, D8, D12, D14: Amber; LED_0805_2012Metric
Q15, Q16: DDC114YU-7-F; SOT-363_SC-70-6
R3, R4, R9, R10: 200; R_0805_2012Metric
R5, R6, R11, R12, R28, R30, R31, R32: 100; R_0805_2012Metric
R7, R8, R25, R26: 10k; R_0805_2012Metric
U2: 74HC7014; SOIC-14_3.9x8.7mm_P1.27mm

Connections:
+5V: D5.1 (K), D7.1 (K), D11.1 (K), D13.1 (K), Q15.3 (C1), Q15.6 (C1), Q16.3 (C1), Q16.6 (C1), R5.1, R6.1, R11.1, R12.1; also elsewhere on the board
/A4/SDA: R28.2; also elsewhere on the board
/A5/SCL: R30.2; also elsewhere on the board
/A6: R31.2; also elsewhere on the board
/A7: R32.2; also elsewhere on the board
/Button_Debounce/Mode_Raw: D5.2 (A), D9.1 (K), R5.2, R7.1; also elsewhere on the board
/Button_Debounce/TrigL_Raw: D13.2 (A), D16.1 (K), R12.2, R26.1; also elsewhere on the board
/Button_Debounce/TrigR_Raw: D11.2 (A), D15.1 (K), R11.2, R25.1; also elsewhere on the board
/Button_Debounce/TrigS_Raw: D7.2 (A), D10.1 (K), R6.2, R8.1; also elsewhere on the board
GND: C3.2, C4.2, C5.2, C6.2, D9.2 (A), D10.2 (A), D15.2 (A), D16.2 (A), R3.2, R4.2, R9.2, R10.2, U2.3, U2.11; also elsewhere on the board
unnamed: C3.1, R7.2, U2.13
unnamed: C4.1, R8.2, U2.1
unnamed: C5.1, R25.2, U2.9
unnamed: C6.1, R26.2, U2.5
unnamed: D6.2 (A), Q16.4 (E1)
unnamed: D6.1 (K), R3.1
unnamed: D8.2 (A), Q16.1 (E1)
unnamed: D8.1 (K), R4.1
unnamed: D12.2 (A), Q15.1 (E1)
unnamed: D12.1 (K), R9.1
unnamed: D14.2 (A), Q15.4 (E1)
unnamed: D14.1 (K), R10.1
unnamed: Q15.5 (B1), R30.1, U2.8
unnamed: Q15.2 (B1), R28.1, U2.6
unnamed: Q16.5 (B1), R31.1, U2.12
unnamed: Q16.2 (B1), R32.1, U2.2

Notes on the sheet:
Button Indication
Unused Gates
Button Debounce

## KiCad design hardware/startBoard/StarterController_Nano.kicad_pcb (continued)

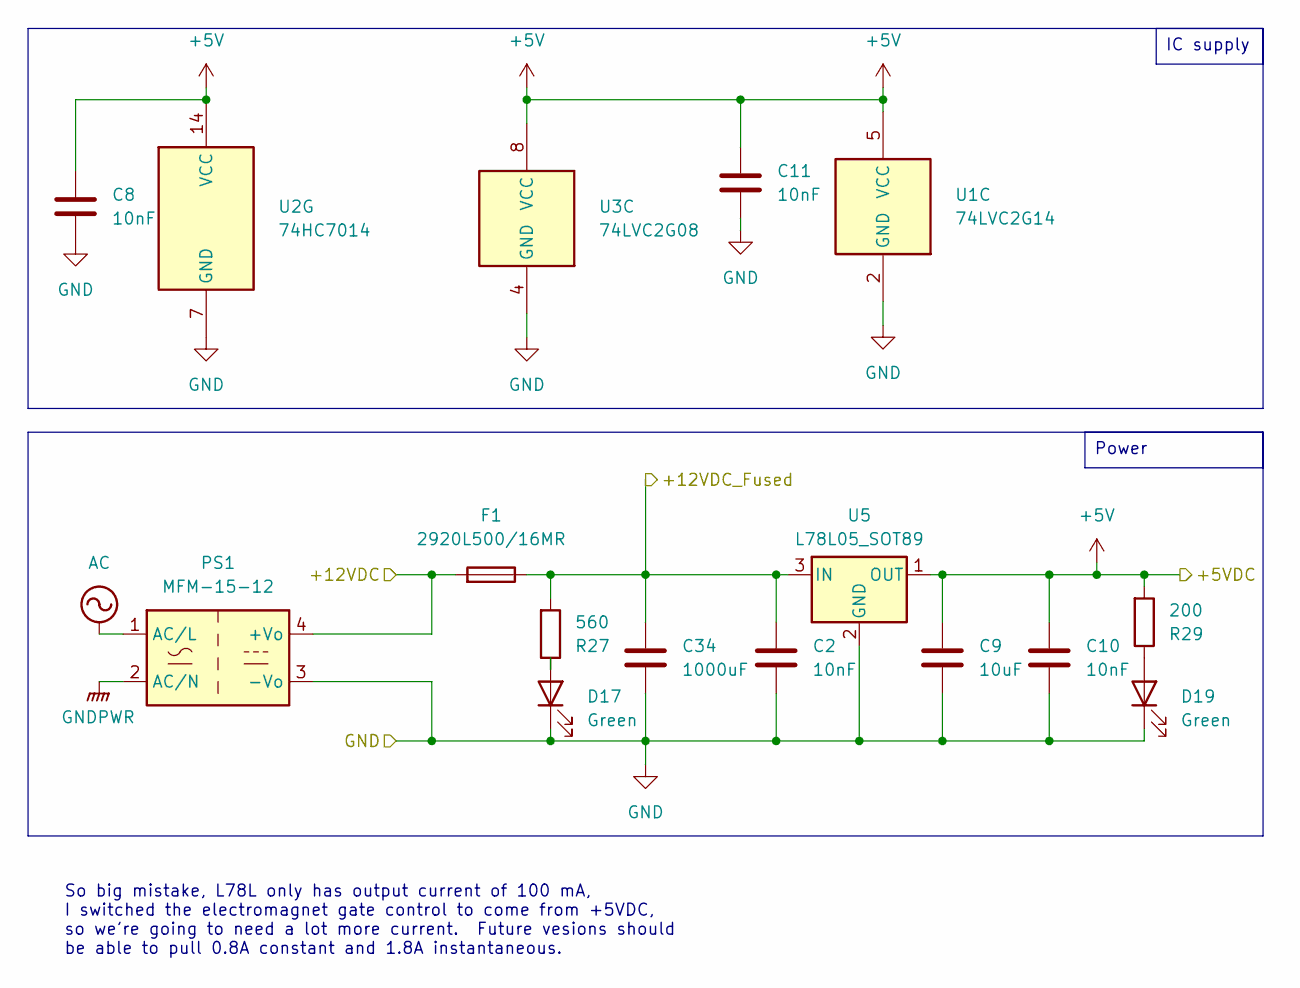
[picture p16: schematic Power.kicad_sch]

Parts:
C2, C8, C10, C11: 10nF; C_0805_2012Metric
C9: 10uF; C_0805_2012Metric
C34: 1000uF; C_Elec_10x10.2
D17, D19: Green; LED_0805_2012Metric
F1: 2920L500/16MR; Fuse_2920_7451Metric
PS1: MFM-15-12; Converter_ACDC_MeanWell_MFM-15-xx_THT
R27: 560; R_0805_2012Metric
R29: 200; R_0805_2012Metric
U1: 74LVC2G14; SOT-363_SC-70-6
U2: 74HC7014; SOIC-14_3.9x8.7mm_P1.27mm
U3: 74LVC2G08; SSOP-8_2.95x2.8mm_P0.65mm
U5: L78L05_SOT89; SOT-89-3

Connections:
+5V: C8.1, C9.1, C10.1, C11.1, R29.2, U1.5 (VCC), U2.14 (VCC), U3.8 (VCC), U5.1 (OUT); also elsewhere on the board
+12V: C2.1, C34.1, F1.1, R27.2, U5.3 (IN); also elsewhere on the board
/Power/+12VDC: F1.2, PS1.4 (+Vo); also elsewhere on the board
GND: C2.2, C8.2, C9.2, C10.2, C11.2, C34.2, D17.1 (K), D19.1 (K), PS1.3 (-Vo), U1.2 (GND), U2.7 (GND), U3.4 (GND), U5.2 (GND); also elsewhere on the board
unnamed: D17.2 (A), R27.1
unnamed: D19.2 (A), R29.1

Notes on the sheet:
So big mistake, L78L only has output current of 100 mA, I switched the electromagnet gate control to come from +5VDC, so we're going to need a lot more current. Future vesions should be able to pull 0.8A constant and 1.8A instantaneous.
IC supply
Power

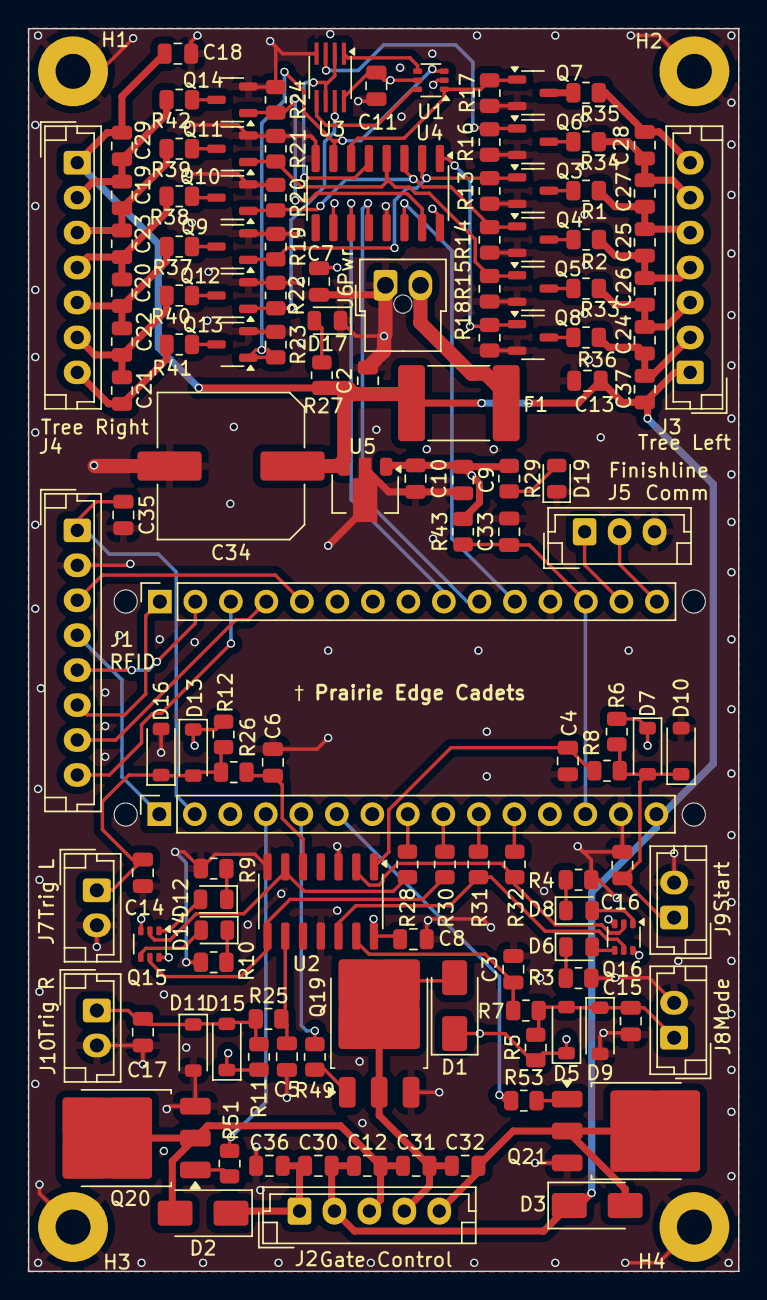
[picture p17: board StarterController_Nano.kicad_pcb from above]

Board: 4 copper layers, 50.8 x 88.9 mm, 142 parts (0 on the bottom side), 88 nets.

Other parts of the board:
MH1, MH2, MH3, MH4: MountingHole_65mil

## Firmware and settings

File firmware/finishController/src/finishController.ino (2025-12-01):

#include "sensors.h"
#include "globals.h"
#include "serialComm.h"
#include "display.h"

bool needReact 			= false;		// Flag to indicate if reaction time is needed
raceMode currentMode;

// Results structure for a lane.  Times are stored in microseconds
struct raceResults {
	bool		left;			// indicates track left(true) or right(false);
    bool		foul;			// whether a foul occurred (false start)
    bool		winner;			// true if this lane won the race
    uint32_t	carTimeUs;		// computed car time including or excluding reaction
    uint32_t	raceTimeUs;		// raw finish time from sensors
    uint32_t	reactionTimeUs;	// reaction time measured at start
};

struct StateMachine {
	raceState current;
	raceState target;
	bool entry;
	bool exit;
	bool allowedTransition(raceState next) {
		// Allowed transitions table (FROM x TO)
		static constexpr bool allowed[6][6] = {
		/* FROM\TO:  IDLE STAG CNTD RACE CMPL TEST */
 		/*IDLE*/     {0,   1,   0,   0,   0,   1},
 		/*STAGING*/  {0,   0,   1,   0,   0,   0},
 		/*COUNTDOWN*/{0,   0,   0,   1,   0,   0},
 		/*RACING*/   {0,   0,   0,   0,   1,   0},
 		/*COMPLETE*/ {1,   0,   0,   0,   0,   0},
 		/*TEST*/     {1,   0,   0,   0,   0,   0}
		};

		return allowed[current][next];
	};

	// Returns true when transition is complete
    void selfTransition(raceState newState) {
		// 1. Reject illegal transitions
        if (!allowedTransition(newState)) {
			return false;
		}

		// 2. Check if already in target state
        if (current == newState) {
            return true;
        }

		// 3. Set intention to transition
		target = newState;

		// 4. Attempt coordinated change
		txStatus result	= txRaceState(target);
		switch (result) {
			
			case TX_ACKED:
				// Transition has been confirmed, now commit
				entry 	= true;		// next loop: run entry logic
				current	= target;   // commit new state
				exit 	= true;   		// run exit logic
				resetTxState(MSG_RACE_STATE);
				return true;

			case TX_TIMEOUT:
			case TX_FAILED:
				// Transition failed, revert intention and abandon transition
				target	= current;
				resetTxState(MSG_RACE_STATE);
				return false;

			default:
				// Still TX_SENT or waiting for ACK
				return false;
		}

        return true;  // Already in target state
    }

    bool isStateTxInFlight() const {
        const auto& s = txState[MSG_RACE_STATE];  // from serialComm
        return (s.status == TX_SENT);
    }

    void rxTransition(raceState newState) {
		// 1. Abort current state transition if new rx received
		if (isStateTxInFlight()) {
			resetTxState(MSG_RACE_STATE);
		}

		// 2. Check if already in target state
        if (current == newState) {
            return true;
        }

		// 3. Commit local state change
		target 			= newState;
		current			= newState;
		entry  			= true;
		exit   			= true;
		return true;
	}
};

struct RaceTimingData {
    uint32_t raceStartUs;
    uint32_t leftTimeUs;
    uint32_t rightTimeUs;
    bool leftRecorded;
    bool rightRecorded;
};

// Static instances for left and right lanes; lifetime extends over loops.
static raceResults leftResults	= {true, false, false, 0, 0, 0};
static raceResults rightResults	= {false, false, false, 0, 0, 0};
static StateMachine stm			= {RACE_IDLE, RACE_IDLE, true, false};
static RaceTimingData race		= {0, 0, 0, false, false};

void setup() {
	setupSerial();
	setupSensors();
	setupDisplay();	
	// Start in idle state.  These variables are declared in globals.h.
    stm.current					= RACE_IDLE;
    stm.target					= RACE_IDLE;
    currentMode 				= MODE_GATEDROP;
}

void loop() {
	rxSerial();
	switch(stm.current) {
		case RACE_IDLE:
			if(stm.entry){
				stm.entry 			= false;
				clearDisplay(true);				// clear display (left)
				clearDisplay(false);			// clear display (right))
			}

			if (rxMode != currentMode){
				currentMode 		= rxMode;	// update mode from serial, source will validate
				// notifyBLEMode(currentMode);	// Future - notify mode change over BLE
			}
			stm.rxTransition(rxState);			// transitions state if received via serial
			if(stm.exit){
				stm.exit 			= false;
			}

			break;
			
		case RACE_STAGING:
			if(stm.entry){
				stm.entry 			= false;
			}
			stm.rxTransition(rxState);			// transitions state if received via serial
			if(stm.exit){
				stm.exit 			= false;
			}

			break;
			
		case RACE_COUNTDOWN:
			if(stm.entry){
				stm.entry 			= false;
				rxRaceStart			= false;
				race.raceStartUs	= 0;
			}

			if (rxRaceStart && (race.raceStartUs == 0)) {
				race.raceStartUs	= micros();
				armSensors(race.raceStartUs);
			}
			stm.rxTransition(rxState);						// transitions state if received via serial	
			if(stm.exit){
				stm.exit 			= false;		
			}

			break;
			
		case RACE_RACING:
			if(stm.entry){
				// Reset recording flags and times
				race.leftRecorded		= false;
				race.rightRecorded		= false;
				race.leftTimeUs			= 0;
				race.rightTimeUs		= 0;
				rxRightReactionTime		= -1;
				rxLeftReactionTime		= -1;
				rxLeftFoul				= false;
				rxRightFoul				= false;
				stm.entry 				= false;
				// Only arm if not already armed from COUNTDOWN state
				if (race.raceStartUs	== 0){
					race.raceStartUs 	= micros();
					armSensors(race.raceStartUs);
				}
			}

			handleSensors();					// check for interrupt and record finish time
			handleRxReaction();					// store reactio and foul from rxSerial

			if (race.leftRecorded && race.rightRecorded) {
				stm.target	= RACE_COMPLETION;	// initiate state transition when both sensors recorded
			}
			stm.selfTransition(stm.target);			// transitions state if updated target
			
			if(stm.exit){
				stm.exit 				= false;	
				disarmSensors();	
			}
			break;
			
		case RACE_COMPLETION:
			if(stm.entry){
				needReact				= false;	// clear flag for safety
				rxDisplayAdvanceFlag	= false;	// clear flag for safety
				computeRaceTimes();					// calculate and compile race times, reaction times, and winner
				transmitWinnerToSC();				// send winner over serial to startController
				displayCarTimes();					// push car times to display
				stm.entry 				= false;	// done with stm.entry tasks
			}

			if(rxDisplayAdvanceFlag) {
				// When startControll signals to advance display (start trigger)
				if(needReact){
					displayReactionTimes();
				} else {
					stm.target			= RACE_IDLE;
				}
				rxDisplayAdvanceFlag	= false;
			}
			stm.selfTransition(stm.target);				// transitions state if updated target

			if(stm.exit){
				stm.exit 				= false;
				// carID, left, foul, winner, carTimeUs, raceTimeUs, reactionTimeUs
				leftResults		= {true,	false,	false,	0,	0,	0};		// reset left results struct
				rightResults	= {false,	false,	false,	0,	0,	0};		// reset right results struct
			}
			break;
			
		case RACE_TEST:
			// currently unused, just transition back to idle
			if(stm.entry){
				stm.target 		= RACE_IDLE;
				stm.entry 		= false;
			}
			
			stm.selfTransition(stm.target);				// transitions state if updated target

			if(stm.exit){
				stm.exit 		= false;
			}
			break;
	}	
}

/* =========================================================================
 *                        RACE_IDLE HELPER FUNCTIONS
 * ========================================================================= */
 
 /* =========================================================================
 *                        RACE_STAGING HELPER FUNCTIONS
 * ========================================================================= */

/* =========================================================================
 *                        RACE_COUNTDOWN HELPER FUNCTIONS
 * ========================================================================= */

/* =========================================================================
 *                        RACE_RACING HELPER FUNCTIONS
 * ========================================================================= */
void handleSensors() {
	uint32_t now = micros();
	uint32_t elapsed = now - race.raceStartUs;
	
    if (!race.leftRecorded) {
		// If the left sensor has finished, save finish time.
		if (isLeftFinished()) {
			race.leftTimeUs  	= getLeftTimeUs();
			race.leftRecorded 	= true;
		// If max race time exceeded, save finish time.
		} else if (elapsed > config.maxRaceTimeUs) {
			race.leftTimeUs 		= config.maxRaceTimeUs;
			race.leftRecorded 	= true;
		}
    }
	
	if (!race.rightRecorded) {
		// If the left sensor has finished, save finish time.
		if (isRightFinished()) {
			race.rightTimeUs  	= getRightTimeUs();
			race.rightRecorded 	= true;
		// If max race time exceeded, save finish time.
		} else if (elapsed > config.maxRaceTimeUs) {
			race.rightTimeUs 	= config.maxRaceTimeUs;
			race.rightRecorded 	= true;
		}
    }
}

void handleRxReaction() {
	if (rxLeftReactionTime >= 0) {
		leftResults.reactionTimeUs 	= (uint32_t)rxLeftReactionTime;
		rxLeftReactionTime 			= -1;		// reset flag
	}
	if (rxRightReactionTime >= 0) {
		rightResults.reactionTimeUs	= (uint32_t)rxRightReactionTime;	
		rxRightReactionTime 		= -1;		// reset flag
	}
	if (rxLeftFoul) {
		leftResults.foul			= true;
		rxLeftFoul					= false;	// reset flag
	}
	if (rxRightFoul) {
		rightResults.foul			= true;
		rxRightFoul					= false;	// reset flag
	}
	
}

/* =========================================================================
 *                        RACE_COMPLETION HELPER FUNCTIONS
 * ========================================================================= */
void computeRaceTimes() {
	// race time is the raw time from GO to FINISH
	leftResults.raceTimeUs	= race.leftTimeUs;
	rightResults.raceTimeUs	= race.rightTimeUs;
	
	// carTime is raceTime with reactionTime
	// foul indicates addition (trigger before GO) so multiply by +1
	// no foul indicates subtraction (trigger after GO) so multiply by -1
	leftResults.carTimeUs  = leftResults.raceTimeUs  + (leftResults.foul  ? +1 : -1) * leftResults.reactionTimeUs;
	rightResults.carTimeUs = rightResults.raceTimeUs + (rightResults.foul ? +1 : -1) * rightResults.reactionTimeUs;
	
	// cannot win if foul, if both foul no winner (tie).  If no foul fastest carTime wins
	leftResults.winner  = !leftResults.foul  && (rightResults.foul || (leftResults.carTimeUs  < rightResults.carTimeUs));		// winner if no foul AND (other track fouls OR faster time)
	rightResults.winner = !rightResults.foul && (leftResults.foul  || (rightResults.carTimeUs < leftResults.carTimeUs));		// winner if no foul AND (other track fouls OR faster time)
}

void transmitWinnerToSC(){
	// Determine the winner mask: bit0=L, bit1=R, bit2=tie.
	uint8_t winnerMask = 0;
	if (leftResults.winner)  winnerMask |= 0b0001;
	if (rightResults.winner) winnerMask |= 0b0010;
	if (!leftResults.winner && !rightResults.winner) {
		// Neither flagged winner – treat as tie.
		winnerMask |= 0b0100;
	}
	static bool txWin = true;
	while (txWin) {
		txStatus win = txWinner(winnerMask);
		switch (win) {
			case TX_ACKED:										
				txWin 		= false;						// winner transmission no longer pending
				resetTxState(MSG_WINNER);
				break;
			case TX_TIMEOUT:
			case TX_FAILED:
				txWin 		= false;						// winner transmission failed
				resetTxState(MSG_WINNER);					// reset transmit message
				// future: flash red lights for error; updateLights(LIGHT_FL | LIGHT_FR);
				// future: log / transmit state transition error
				break;
			case TX_NONE:
			case TX_SENT:
			case TX_NACKED:
			default:
				break;
		}
	}
}

static void displayCarTimes() {	
	updateDisplay(leftResults.carTimeUs, true);
	updateDisplay(rightResults.carTimeUs, false);
	
	if(currentMode != MODE_GATEDROP){
		needReact			= true; 		// set flag to display reaction times next
	}
}

static void displayReactionTimes() {	
	updateDisplay(leftResults.reactionTimeUs, true);
	updateDisplay(rightResults.reactionTimeUs, false);
}

/* =========================================================================
 *                        GENERIC HELPER FUNCTIONS
 * ========================================================================= */

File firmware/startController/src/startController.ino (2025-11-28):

/*
 * Pinewood Derby Track Start Controller
 * Version: 1.0
 * Author: Darren Schaaf
 * Date September 2025
 * Compile: Arduino IDE 1.8+ or PlatformIO
 * Board: Arduino Nano
 * Libraries Required:
 */

#include <Arduino.h>
#include "lights.h"
#include "gates.h"
#include "serialComm.h"
#include "buttons.h"
#include "globals.h"

// State machine structure for managing state transitions
struct StateMachine {
	raceState current;
	raceState target;
	bool entry;
	bool exit;
	// Returns true when transition is complete
	bool transition(raceState newState) {
		if (!isValidStateTransition(newState)){
			return false;					// Invalid transition
		}
		if (target != newState) {
			target = newState;				// Set intention
		}
		if (current != target) {
			// Try to coordinate transition
			txStatus result = txRaceState(target);
			switch (result) {
				case TX_ACKED:
					entry = true;			// Enter new state
					current = target;		// Commit transition
					exit = true;			// Exit previous state
					resetTxState(MSG_RACE_STATE);
					return true;
				case TX_TIMEOUT:
				case TX_FAILED:
					target = current;		// Abandon transition
					resetTxState(MSG_RACE_STATE);
					// Log error or flash lights
					return false;
				default:
					return false;			// Still pending
			}
		}
		return false;						// Already in target state
	}
	// Handle unsolicited state changes from rxSerial
	void rxTransition(raceState rxState) {
		if (rxState != current) {
			transition(rxState);
		}
	}
	// Add state validation
	bool isValidStateTransition(raceState to) {
		switch(current) {
        	case RACE_IDLE:			return (to == RACE_STAGING 		|| to == RACE_TEST);
        	case RACE_STAGING:		return (to == RACE_COUNTDOWN	|| to == RACE_IDLE);
        	case RACE_COUNTDOWN:	return (to == RACE_RACING);
        	case RACE_RACING:		return (to == RACE_COMPLETE);
        	case RACE_COMPLETE:		return (to == RACE_IDLE);
			case RACE_TEST:			return (to == RACE_IDLE);
        	default:				return false;
    	}
	}
};

// Mode machine structure for managing mode transitions
struct ModeMachine {
	raceMode current;
	raceMode target;
	bool transition(raceMode newMode) {
		// Returns true when transition is complete
		if (target != newMode) {
			target = newMode;					// Set intention
		}
		if (current != target) {
			// Try to coordinate transition
			txStatus result = txRaceMode(target);
			switch (result) {
				case TX_ACKED:
					current = target;			// Commit transition
					resetTxState(MSG_RACE_MODE);
					return true;
				case TX_TIMEOUT:
				case TX_FAILED:
					target = current;			// Abandon transition
					resetTxState(MSG_RACE_MODE);
					// Log error or flash lights
					return false;
				default:
					return false;				// Still pending
			}
		}
		return false;							// Already in target mode
	}
	void nextMode() {
		// Determine next mode in sequence for button press
		switch(current) {
			case MODE_GATEDROP:	target	= MODE_REACTION;	break;
			case MODE_REACTION:	target	= MODE_PRO;			break;
			case MODE_PRO:		target	= MODE_GATEDROP; 	break; // DIALIN not yet defined, will be next = MODE_DIALIIN;
			case MODE_DIALIIN:	target	= MODE_GATEDROP;	break;
			default: 			target	= MODE_GATEDROP;	break;
		}
	}
	void rxTransition(raceMode serialTgt) {
		if (serialTgt != current) {									// Unsolicited mode change from serial
			transition(serialTgt);
		}
	}
};



// globals.h definitions
unsigned long leftReactionTime			= 0;			// Reaction time for left track
unsigned long rightReactionTime			= 0;			// Reaction time for right track
unsigned long raceStartTime				= 0;			// Log the start time of the race
unsigned long leftStartTime				= 0;			// Log the start time of the left track
unsigned long rightStartTime			= 0;			// Log the start time of the right track
bool leftFoul							= false;		// Log foul status of left track
bool rightFoul							= false;		// Log foul status of right track

static_assert(UID_LEN == serialUIDLength, "UID Lengths Must Match");

// State & mode machine instances
static StateMachine stm					= {RACE_IDLE, RACE_IDLE, true, false};
static ModeMachine mdm					= {MODE_GATEDROP, MODE_GATEDROP};

// countdown 
static countdownState cdState			= CD_IDLE;		// current countdownState value - see globals.h
static countdownState prevCdState		= CD_IDLE;		// previous countdownState
static unsigned long cdTimer			= 0;			// countdown timer
static unsigned long stageDelay			= 500;			// default delay between staging sequences
static bool pendStartTx					= false;		// marker for if start transmission is pending

// racing
static bool reactLeftPending			= false;		// marker for if left reaction tx is pending
static bool reactRightPending			= false;		// marker for if right reaction tx is pending
static bool foulStatusPending			= false;		// marker for if foul status tx is pending
static unsigned long startDelay			= 0;			// Unused, delay between start and ACK

// results
static bool winLightsPend				= false;		// marker if result lights need to display
static bool dispAdv						= false;		// marker for pending tx display advance

// button management
static bool startReleased				= true;
static bool modeReleased				= true;


// Helper function to manage countdown timing based on race mode
countdownState tickCountdownState(raceMode mode, countdownState cdState){
	unsigned long currentTime = millis();
	switch (cdState) {
		case CD_STAGED:
			if (mode == MODE_PRO){
				stageDelay = 400;
				cdState = CD_Y1;
			} else {
				stageDelay = 500;
				cdState = CD_Y3;
			}
			cdTimer = currentTime;
			break;
		case CD_Y3:
			if (currentTime - cdTimer >= stageDelay){
				cdState = CD_Y2;
				cdTimer = currentTime;
			}
			break;
		case CD_Y2:
			if (currentTime - cdTimer >= stageDelay){
				cdState = CD_Y1;
				cdTimer = currentTime;
			}
			break;
		case CD_Y1:
			if (currentTime - cdTimer >= stageDelay){
				cdState = CD_GO;
				cdTimer = currentTime;
			}
			break;
		default:
			break;
	}
	return cdState;	
}

// Helper function to calculate elapsed microseconds with overflow protection
unsigned long elapsedMicros(unsigned long startTime, unsigned long endTime) {
    if (endTime >= startTime) {
        return endTime - startTime;  					// Normal case
    } else {
        return (0xFFFFFFFF - startTime) + endTime + 1;	// Overflow case
    }
}

void setup(){
	setupSerial();
	setupButtons();
	setupGates();
	setupLights();
}
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

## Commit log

2025-10-03 Initial commit/hardware
    [Arm_Magnet_Holder.step, Button_Debounce.kicad_sch, Digit_Demux_L.kicad_sch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]
2025-10-04 Changed c++ to .ino for Arduino IDE compatibity
2025-11-03 Finish Control Board completion for order
    [Digit_Demux.kicad_sch, Digit_Demux_L.kicad_sch, Digit_Demux_R.kicad_sch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]
2025-11-28 Update BOM export settings in KiCad project
    Configured BOM export filename and adjusted BOM field settings in FinishControllerBoard_v1.kicad_pro. Now includes additional fields, changes grouping, and includes excluded-from-BOM items. Added loc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
2025-12-02 SC: Restructure to match FC for Arduino and generic compiling
2026-02-21 startController schematic never committed, oops
    [StarterController_Nano.kicad_sch]
2026-02-27 Put ascii connector layout on peripheral tests
2026-04-28 deleted nested folder, keep an eye on schematics
    [StarterController_Nano.kicad_sch]
2026-05-05 Paid some technical debt, squashed some bugs, lots of changes made here to structure.
    [display.cpp, lights.cpp]
2026-05-05 Fix compile error and type mismatch found in code review
    - serialComm.h: rename struct field rxID -> ID to match all access
    sites in serialComm.cpp (rx.ID); mismatch was a compile error
    - serialComm.cpp: pass array by name (payload) not address (&payload)
    in txReactionTime; &array has type uint8_t(*)[4], not uint8_t*
    - display.cpp: update clamp comment to explain why 99998 not 99999:
    input of 99999500 µs rounds to 100000 ms (6 digits, overflow)
    [display.cpp]
2026-05-08 refactor: shared stateMachine.h, raceTypes.h, decouple serialComm, fix arduino-cli build
    - Rename globals.h to raceTypes.h (enums only; bitmasks moved to serialComm.h)
    - raceTypes.h is self-contained: adds #include <stdint.h> for uint8_t base types
    - Decouple serialComm from race types: txRaceMode/txRaceState now take uint8_t
    - Extract duplicated stateMachine struct into firmware/lib/shared/stateMachine.h
    - Add library.properties; fix .ino include paths; update CLAUDE.md --library flag
    - Add .vscode/tasks.json for Ctrl+Shift+B arduino-cli compile in VS Code
    - Update docs and PlantUML diagram to reflect new file names and architecture
    - Close P0-1 (MSG_LEFT_RESULT stale doc) and P0-3 (arduino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
    [finishController.ino, lights.cpp, startController.ino]
2026-05-13 eaction time sentinel → bool flags | Replaced `int32_t = -1`
2026-05-21 improved the gates interface and calls by switching to a global lane enum, and making deeper function calls that keep gate hw logic out of main stm.
2026-05-21 small cleanup on interrupt edge from compile test
2026-05-25 Improved the code to reset all local heat data on entry to idle state instead of scattered messages and commands throught the code.
2026-05-26 more cleanly handled the case where a car never crosses the finish line and instead of just assigning maxracetime we actually record a DNF and mark the time as invalid.
2026-05-26 Fix P1-12: replace criticalTxError halts with forceIdle() abort path
    Add forceIdle() to stateMachine: directly resets local state to IDLE
    and fires best-effort MSG_RACE_STATE(IDLE) without waiting for ACK.
    Other controller follows if it receives the notification, or recovers
    via its own timeout/DNF paths.
    Fix silent table bug: STAGING→IDLE was missing despite the coordination
    model requiring it — Mode button in STAGING was silently doing nothing.
    Add COUNTDOWN→IDLE and RACING→IDLE as abort paths.
    SC: MSG_RACE_START and MSG_FOUL failures call forceIdle() (heat
    unrecoverable); MSG_LEFT/RIGHT_REACT failures are soft (reaction times
    are record-keeping only in REACTION/PRO, winner is fi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
2026-05-27 Deepen test coverage: inline pure logic, replace 25 stubs with real tests
    Move raceTimingData (startController.h) and computeHeatResults +
    HeatResults/TimingInputs (finishController.h) out of .cpp files and
    into their respective headers as inline definitions. This lets native
    tests include and exercise the logic without linking against
    hardware-dependent translation units.
    Replace all timing, compute, and state-machine test stubs with real
    assertions (25 tests across test_timing, test_compute,
    test_state_machine). Add three serial no-op stubs to
    test_state_machine so stateMachine.h links natively without Arduino.
    Delete test_display and test_lights (15 stubs) — display and light
    bugs sur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
    [derbySerialResponder.ino, derbySerialTester.ino]
2026-06-12 Fable comprehensive review, made updates to the serial messaging affecting stale states, timeouts, switch to bus->available() pointer notation, payload checks, and a few other comm changes.
2026-06-12 Tests: scriptable Arduino.h mock; serialComm engine + display suites; compute/timing edge cases (30->59 tests)
2026-06-12 fwTest + uart_monitor: zero-payload MSG_RACE_START to match protocol
2026-06-12 Docs: wire protocol reference, two-board bench test protocol (P1-19), testing/README accuracy, MIT license
2026-06-12 Track .vscode tasks + extension recommendations; keep machine-specific IDE files ignored
2026-07-01 AD-8: add declare-intent interface (request/service/takeEntry/takeExit) to stateMachine
    Additive only - the coordinated-transition interlock moves inside the machine
    so handlers can't get the ordering wrong (the old P0 failure class).
    test_state_machine now drives the real serial engine: 67/67 L2 tests.
    [test_state_machine.cpp]
2026-07-02 AD-9: SC handlers migrate to the declare-intent state machine interface
    Five copies of the transition ritual become request/service one-liners;
    the RACING data-integrity hold is now the only visible special case.
    modeSelect mirrors the same shape. Behavior unchanged - SC flash
    byte-identical, 67/67 regression tests green.
2026-07-02 AD-10: FC handlers migrate to the declare-intent interface; fix stale exit flag leak
    The migration exposed a latent hazard: an unconsumed exit flag from one
    transition leaked into the next state's takeExit(), which would have
    disarmed sensors at RACING entry. service() now scrubs stale exit each
    pass; new regression test pins it. FC RACING/COMPLETE keep their
    no-edge-consumption behavior via service(true). 68/68 L2 tests.
    [test_state_machine.cpp]
2026-07-02 AD-4: add txResend(id) - retry a failed message from its captured payload
    Retry policy no longer rebuilds payloads; rearm-in-place covers the
    same-pass window where a re-enqueue is silently rejected as a duplicate
    (the existing FC winner retry hits exactly that window and has never
    actually resent - fix lands with the outbox adoption). 72/72 L2 tests.
    [test_serialcomm.cpp]
2026-07-03 AD-5: shared Outbox engine - ADR-0004's abort criteria as a policy table
    One engine replaces two divergent PendingTx poll loops (adoption comes
    next). Const policy rows + runtime bitmasks; verdict reporting keeps
    messaging out of race state; RETRY_ONCE built on txResend. New
    test_outbox suite drives the real serial engine: 81/81 L2 tests.
    [test_outbox.cpp]
2026-07-03 AD-6: SC adopts the shared Outbox - abort policy visible in the main loop
    The hand-written PendingTx flags become a five-row policy table; the
    main loop acts on verdicts (txError + forceIdle) instead of hiding the
    heat reset inside a status check. Wire and abort behavior unchanged:
    81/81 L2 tests, no test edits needed.
2026-07-03 AD-7: FC adopts the shared Outbox - fixes the silent winner-retry no-op
    Closes the outbox chain; both controllers now run one engine off
    one-line policy tables. MSG_WINNER = RETRY_ONCE resends via txResend,
    which survives the same-pass window the old retry never escaped (it
    was rejected as a duplicate every time and never reached the wire).
    winnerMask demoted to a local. 81/81 L2 tests; both builds compile.
2026-07-03 AD-1: extract sensor onBeamBreak core + first test_sensors suite
    The duplicated left/right ISR capture logic becomes one lane-indexed
    onBeamBreak(lane, nowUs); the ISRs are one-line adapters. Passing the
    timestamp in lets the capture rules - armed-check, latch-once, 500 ms
    filter - run on the desktop for the first time. New test_sensors: 8
    tests, 89/89 L2. FC flash byte-identical (pure restructure).
2026-07-03 AD-2: countdown clock injection + test_countdown suite
    CountDownCtx moves to startController.h and tick() takes the current
    time as a parameter instead of reading millis() internally, so the
    tree sequence runs as a table of (time, expected state) rows. New
    test_countdown: 5 tests, 94/94 L2. SC flash byte-identical.
2026-07-04 AD-3: blink + gate clock injection + test_ticks; close P2-8
    updateBlink/updateGates take the current time as an argument, with
    zero-arg wrappers in the headers so call sites are untouched. First
    tests for both modules (test_ticks, 7 tests). P2-8 rider: magic
    numbers in buttons.cpp/lights.cpp become named constexpr. 101/101 L2.
    SC flash -26 B (constexpr conversion; behavior unchanged).
2026-07-25 AD-12: group SerialRxState by field lifecycle; close the AD program
    Every past subtle bug in this struct was a lifecycle misunderstanding -
    a level-triggered value read as though it were an event. The contract is
    now visible per field instead of living in the handler that happens to
    consume it, which is the reference BLE integration will need next.
    Rider: firmware source converted to plain ASCII per file conventions;
    the earlier conversion pass had covered tracked docs only.
    [display.cpp]
2026-07-25 P1-9: countdown stall watchdog + Mode abort; buttons act on release
    The FC already rescued a stalled SC countdown over the link, so the real
    gap was a stall with the link down - hence two SC-local escapes, both via
    forceIdle(), which needs no ACK round-trip to work.
    Folding in the button policy because the bench session exercises these
    interactions next: Start and Mode now act on the release edge through one
    shared detector, replacing three behaviors across five sites. That closes
    a live bug where holding Mode to abort STAGING also advanced the race
    mode on arrival in IDLE. Lane triggers still act on the press - reaction
    timing needs the instant the hand moved.
    [buttons.cpp]
2026-07-25 Document that button debounce is hardware, not software
    architecture.md described buttons.cpp as doing "digital debounce," which
    would invite someone to add a software debounce that the Schmitt triggers
    on the shield already make unnecessary. Also files the countdown abort
    checks under Fault Recovery, where they belong.
2026-07-30 lose P2-39: state Outbox mask intent so the zero-warning gate holds
    The SC's Outbox declaration listed 2 of 4 members, drawing two
    -Wmissing-field-initializers warnings and blocking the shipping
    checklist's zero-warning compile gate. Behavior was already correct --
    omitted aggregate members are value-initialized -- so the fix states
    the intent rather than changing it.
    Applied at all three declaration sites, not just the one that warned,
    because outbox.h's usage example was prescribing the form that warns;
    fixing only the warning site would leave the header teaching the next
    author to reintroduce it.
    Default member initializers were the tidier fix and do not compile: the
    AVR core is pinned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
    [test_outbox.cpp]
2026-10-01 Ignore KiCad autosave, local view-settings, and footprint-cache files so only design sources are tracked.
2026-10-01 First revision of wiring diagrams
2026-10-05 Match Start Controller pin map and button polarity to the as-built board
    First bench run showed the firmware pin map was never checked against
    the PCB: gates are on A0-A2, the shift register clock/latch are D4/D3,
    Start/Mode are A7/A6, and a pressed button reads LOW.
2026-11-03 Adding wiring diagrams for start and finish boards
2026-11-06 Add VS Code upload tasks and a flashing walkthrough so boards can be flashed without remembering arduino-cli syntax
2026-11-06 Add a lean one-operator track integration checklist to prove the full system on the track before permanent board mods Co-Authored-By: Claude Opus 5.5
